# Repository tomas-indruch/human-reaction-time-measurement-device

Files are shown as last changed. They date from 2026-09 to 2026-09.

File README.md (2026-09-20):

# Multi-User Human Reaction Time Measurement Device







A modular, cost-effective mechatronic instrument designed for accurate mental chronometry and psychomotor reaction testing across multiple subjects simultaneously. The system integrates low-latency embedded firmware, dedicated power switching stages for high-intensity visual and acoustic stimuli, and custom ergonomic enclosures.

---

## 📌 Project Highlights
* **Multi-Subject Testing:** Measures up to 8 participants simultaneously with millisecond-level acquisition accuracy, enabling simple, go/no-go, and choice reaction time paradigms.
* **Dual Stimulus Delivery:** High-output visual stimuli (3W power LEDs across four optical wavelengths: 460 nm, 525 nm, 590 nm, 625 nm) and an acoustic buzzer (2048 Hz resonance).
* **Power Electronics Design:** Utilizes IRF540N power MOSFETs with calculated gate current-limiting resistors and pull-down protection to safely switch loads directly from external/USB power rails.
* **In-Situ Parameter Control:** Integrated bi-directional serial interface allowing real-time tuning of fixed/random inter-stimulus intervals (ISI), stimulus modes, and frequencies without test interruption.
* **Field-Tested:** Validated and benchmarked in a secondary school laboratory environment with statistical distribution logging.

---

## 🛠 Hardware Architecture & Schematics

| Component | Specification / Role | Detail |
|---|---|---|
| **MCU** | Arduino UNO R3 | Core timing and USART communication (16 MHz crystal, 0.01% stability) |
| **Power Stages** | 5x IRF540N N-Channel MOSFETs | Fast low-side switching for 3W LEDs and passive buzzer |
| **Visual Stimuli** | 4x High-Power 3W LEDs | Blue (460 nm), Green (525 nm), Yellow (590 nm), Red (625 nm) |
| **Acoustic Stimulus** | 5V Passive Magnetic Buzzer | Frequency adjustable via MCU PWM; 85 dB SPL @ 10 cm |
| **Input Buttons** | 8x Sanwa OBSF-30 Arcade Switches | Low-travel, momentary snap-in switches mapped to dedicated digital/analog pins |
| **Enclosures** | Custom FDM 3D Printed Parts | Protective module cases, button pods, and magnetic stimulus bracket |

### Electrical Design Consideration
To protect the MCU GPIO pins from excessive current spikes caused by gate input capacitance, series gate resistors ($R_G = 270\,\Omega$) were calculated using Ohm's law:

$$R_G \ge \frac{U_{pin}}{I_{max}} = \frac{5\,\text{V}}{0.02\,\text{A}} = 250\,\Omega$$

Static discharge and unintended gate floating are suppressed via $10\,\text{k}\Omega$ pull-down resistors between gate and drain/ground.

---

## 💻 Firmware & Data Acquisition Pipeline

[ Stimulus Trigger ] ──> [ Timer Start (millis) ] ──> [ Pin Change Polling (8 Channels) ]
                                                                   │
[ USART Data Stream (9600 Baud) ] <── [ Fixed/Dynamic Delay ] <────┘
            │
            ▼
[ Real-Time Data Acquisition & Statistical Analysis in Excel ]

## Future Improvements & Industrial Scaling
While the current iteration relies on software polling and millis() for rapid prototyping, a production-grade V2 would utilize Hardware Timers and Pin Change Interrupts (PCINT) to ensure true deterministic measurement and eliminate software execution jitter.

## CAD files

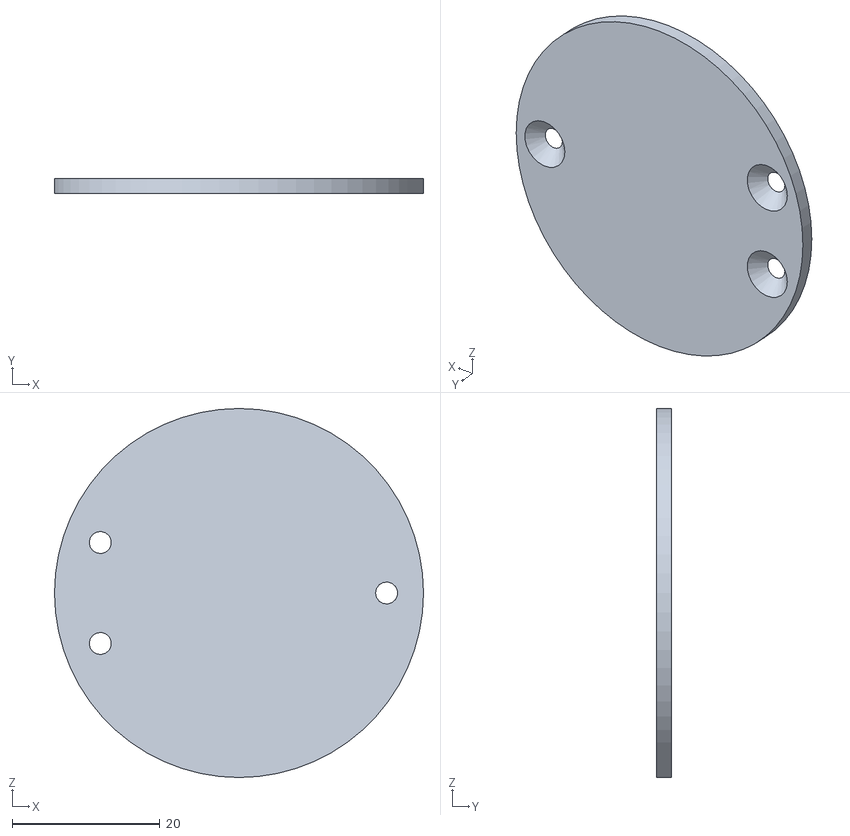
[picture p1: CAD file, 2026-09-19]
CAD/tlacitko_2.stl
50.0 x 2.00 x 50.0

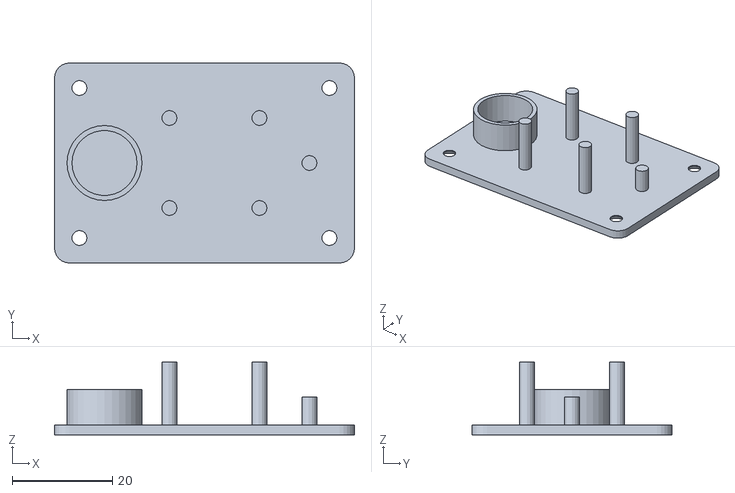
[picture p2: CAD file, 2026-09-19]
CAD/kryt_stimul_2.stl
60.0 x 40.0 x 14.5

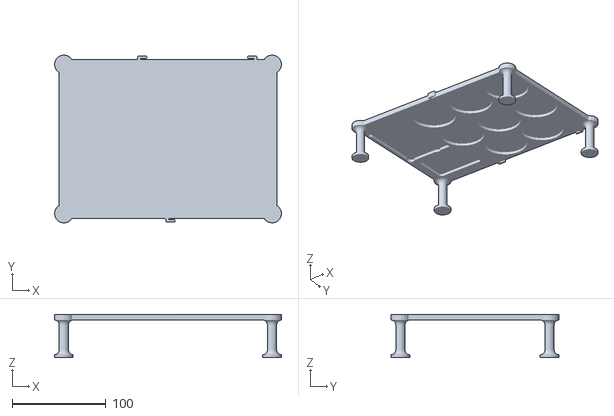
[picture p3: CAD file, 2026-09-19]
CAD/podnos.stl
242.0 x 179.0 x 46.0

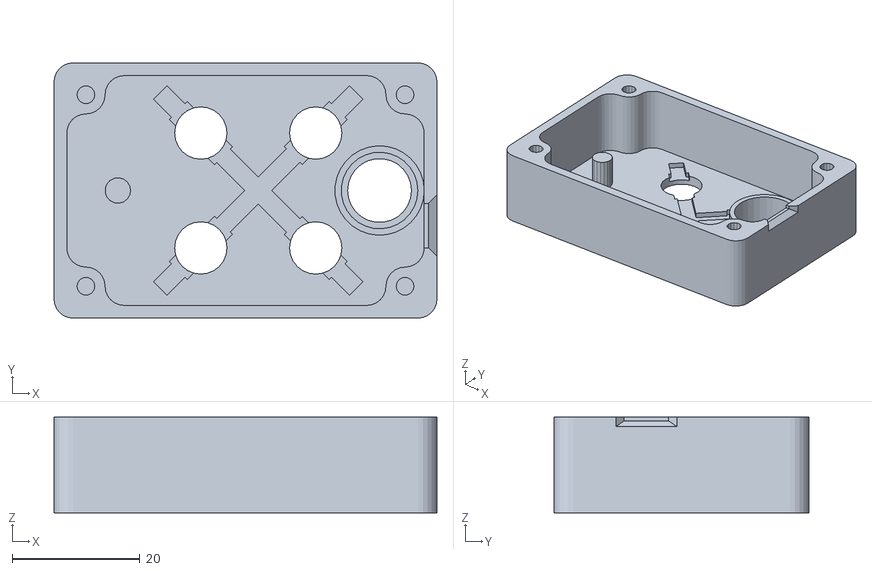
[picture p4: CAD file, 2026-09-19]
CAD/kryt_stimul.stl
60.0 x 40.0 x 15.0

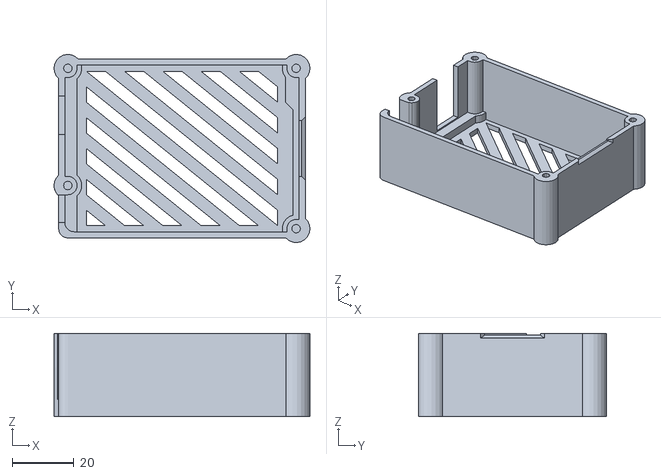
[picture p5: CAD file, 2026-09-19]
CAD/kryt_arduino.stl
83.0 x 61.0 x 27.0

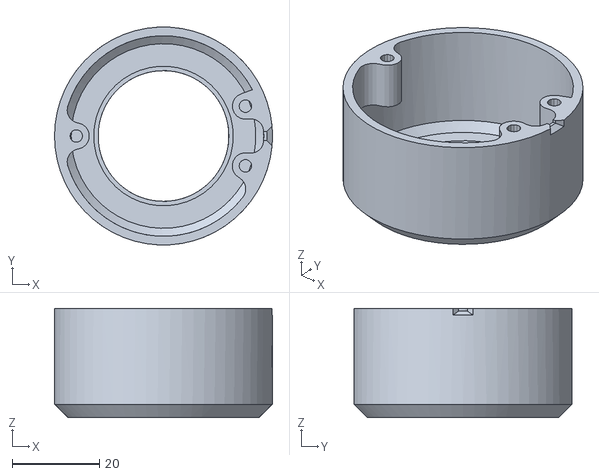
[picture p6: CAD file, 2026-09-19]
CAD/tlacitko.stl
50.0 x 49.9 x 25.0

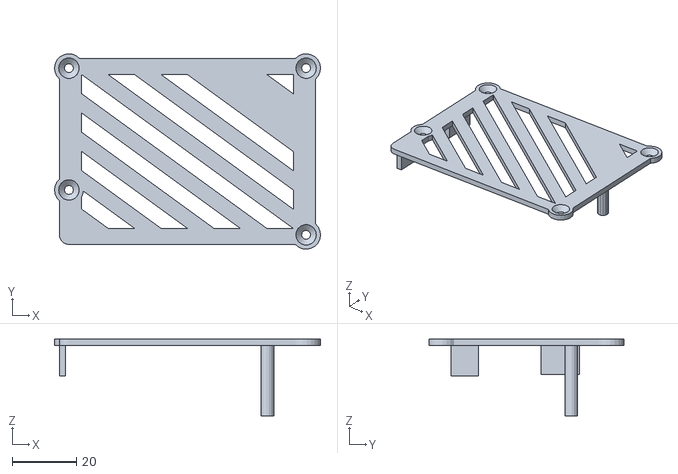
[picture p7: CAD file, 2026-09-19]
CAD/kryt_arduino_2.stl
83.0 x 61.0 x 24.0

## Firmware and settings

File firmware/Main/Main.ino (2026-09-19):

const int buttons[] = {15, 16, 17, 18, 8, 9, 10, 11}; // Tlačítka přiřazeny k pinům
bool flags[] = {0, 0, 0, 0, 0, 0, 0, 0}; // Indexy, zda již bylo tlačítko stisknuto
long time[] = {0, 0, 0, 0, 0, 0, 0, 0}; // Naměřené hodnoty RD
const int leds[] = {2, 3, 4, 5};  // LED diody přiřazeny k pinům
const int buzzer = 6; // Bzučák přiřazen na pin
long start; // Referenční hodnota počátku měření

// Nastavení počátečních podmínek 
int colour = 3;
int frequency = 0;
int stay = 4000;
int variability = 0;

void setup() {
  // Zahájení sériové komunikace
  Serial.begin(9600);
  Serial.setTimeout(10);

  // Nastavení vstupů a výstupů Arduina
  pinMode(buzzer, OUTPUT);

  for (int i = 0; i < 4; i++) {
    pinMode(leds[i], OUTPUT);
  }

  for (int i = 0; i < 8; i++) {
    pinMode(buttons[i], INPUT_PULLUP);
  }
}

void loop() {
  // Počátek měření, kdy se zapne stimul a zaznamená referenční hodnota
  start = millis();
  digitalWrite(leds[colour], HIGH);
  tone(buzzer, frequency, 3000);

  // Kontrola stisknutí tlačítek a zapisování časů stisknutí
  while (millis()-start < 3000){
    for (int i = 0; i < 8; i++){
      if (flags[i] == 0 && !digitalRead(buttons[i])){
        time[i] = millis();
        flags[i] = 1;
      }
    }
  }

  // Ukončení stimulu a odeslání dat
  digitalWrite(leds[colour], LOW);
  sendData(time, flags, start);
  
  // Prodleva mezi měřeními
  randomSeed(analogRead(0));
  delay(stay + random(variability));

  // Kontrola nových příchozích dat
  if (Serial.available() > 0)
  {
    getValues();
  }
}

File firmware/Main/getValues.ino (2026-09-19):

void getValues() {
  // Načtení řetězce do proměnné str
  String str = Serial.readStringUntil('\n');

  // Prealokace paměti
  String newValues[5];
  int valueIndex = 0;
  String currentValue = "";

  // Přijme první čtyři hodnoty ze str a uloží je do proměnné newValues
  for (int i = 0; i < str.length(); i++) {
    char currentChar = str.charAt(i);

    if (currentChar != ',') {
      currentValue += currentChar;
    } else {
      newValues[valueIndex] = currentValue;
      valueIndex++;
      currentValue = "";
    }

    if (valueIndex >= 4) {
      break;
    }
  }

  // Přiřadí index požadované barvě diody
  if (newValues[0] == "Red")
  {
    colour = 0;
  }else if (newValues[0] == "Blue")
  {
    colour = 1;
  }else if (newValues[0] == "Green")
  {
    colour = 2;
  }else if (newValues[0] == "Yellow")
  {
    colour = 3;
  }else
  {
    colour = 4;
  }

  // Přiřadí nové hodnoty frekvenci a statické a dynamické prodlevě
  frequency = newValues[1].toInt();
  stay = newValues[2].toInt();
  variability = newValues[3].toInt();

  // Vrátí nové hodnoty do hlavní funkce
  return colour;
  return frequency;
  return stay;
  return variability;
}
